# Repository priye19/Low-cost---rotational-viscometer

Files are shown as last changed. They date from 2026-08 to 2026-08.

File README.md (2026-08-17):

# Low-Cost Rotational Viscometer (LC-RV)

A 3D-printed concentric-cylinder viscometer that reads viscous drag with a $7 load cell on
the cup instead of a rotary transducer on the shaft.



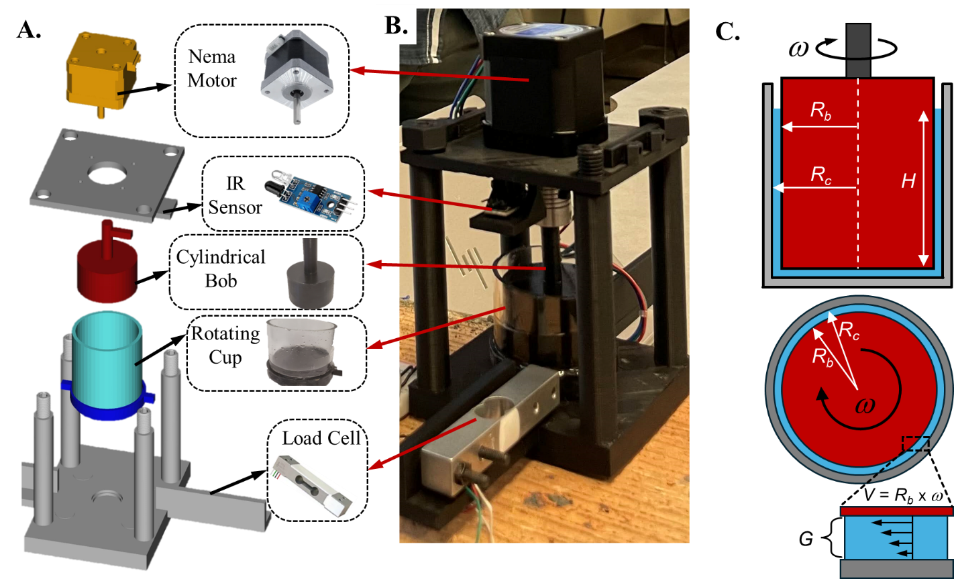
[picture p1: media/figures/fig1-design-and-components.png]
LC-RV design, printed parts and assembled instrument


<sub>Adapted with permission from *J. Chem. Educ.* **2025**, *102* (3), 1138-1145.
Copyright 2025 American Chemical Society.</sub>

## The problem

A bench rotational viscometer costs several thousand dollars. The LC-RV moves the
measurement off the shaft: the cup rides on a bearing so it is free to turn, and a
strain-gauge load cell holds it still and reports the restraining force. Everything else
is a stepper motor, an Arduino Nano, a length of acrylic tube and seven printed parts. It
was built for an undergraduate fluid mechanics course and written up in
*J. Chem. Educ.* (below).

## How it works

A NEMA 17 stepper spins the bob at a set speed inside the stationary cup. Viscous drag in
the annular gap tries to carry the cup round with it; the load cell resists and reads that
drag as a force. An IR sensor on a printed encoder disc reports the bob's actual speed
rather than trusting the step rate. Force, speed and the cell geometry then give the
viscosity:

```
omega = 2*pi*RPM/60
gdot  = omega*Rb/G
tau   = F / A                        A = 2*pi*Rc*h
mu    = tau / gdot
```

With the default 43 mm bob (Rb = 21.5 mm, Rc = 23.0 mm, G = 1.5 mm, h = 30.0 mm) that is
gdot = 14.3333 * omega and A = 4.3354e-3 m^2. Why a narrow gap makes the shear rate
uniform across it, the Taylor-number laminar limit, and what the instrument cannot do are
in [docs/theory.md](docs/theory.md).

## Specifications

| | |
|---|---|
| Bob speed | 5-400 RPM, set by potentiometer, measured by IR tachometer |
| Shear rate | about 7.5-600 s^-1 with the 43 mm bob |
| Viscosity | about 5 mPa·s to 2 Pa·s, the ceiling falling as speed rises |
| Sample volume | about 15 mL with the 43 mm bob |
| Annular gap | 1.5 mm default; 3.0, 4.5 and 6.0 mm bobs also printable |
| Cost | about $90 |

## What it measures

Glycerol solutions from 20 % to 100 % and mineral oil each gave a straight
shear-stress-against-shear-rate line whose slope is the viscosity; liquid soap gave an
apparent viscosity that falls as shear rate rises, which is shear thinning. Absolute
values run low against a commercial rheometer, so trends and orders of magnitude are
sound while individual numbers are not traceable. The bearing-friction floor, the load
cell ceiling and the non-Newtonian caveat are in [docs/theory.md](docs/theory.md).

## Build it

1. Print the core set from `hardware/cad/stl/`. The 40, 37 and 34 mm bobs are optional
   spares for the gap study.
2. Buy the bill of materials in [docs/build-guide.md](docs/build-guide.md).
3. Epoxy the acrylic tube into `cup_bottom`, press in the 608-2RS pivot bearing, and stack
   the frame on the M8 rods.
4. Wire it to `hardware/wiring-diagram.svg` and flash `firmware/LC-RV/`.
5. Run `firmware/calibration/calibrate/` with a known mass on the load cell and paste the
   calibration factor it prints into `firmware/LC-RV/config.h`.

Step-by-step instructions, dimensions and the wiring table are in
[docs/build-guide.md](docs/build-guide.md).

## Repository layout

| Directory | Contents |
|---|---|
| `docs/` | Build guide and the theory behind the equations above |
| `firmware/` | Arduino sketch, `config.h`, and the standalone calibration sketch |
| `hardware/` | Parametric CAD source, 10 STLs (seven for a build, three spare bobs), wiring diagram |
| `software/` | `analyze.py` and its requirements, for the logged CSV |
| `data/` | Reference measurements from the paper, as CSV |
| `media/` | Figures from the paper |

## Citation

If you build this or use these files, cite the article:

> Knutson, M.; Weerakoon, S. P.; Ticknor, C. J.; Yavitt, B. M.; Priye, A. Development and
> Implementation of a Low-Cost 3D-Printed Rotational Viscometer for Rheology and Fluid
> Mechanics Education. *J. Chem. Educ.* **2025**, *102* (3), 1138-1145.
> https://doi.org/10.1021/acs.jchemed.4c01490

`CITATION.cff` carries the same reference in machine-readable form.

## Licence

Code, CAD and documentation in this repository are MIT licensed; see [LICENSE](LICENSE).
The figures in `media/figures/` are reproduced from the article above and remain copyright
of the American Chemical Society. They are not covered by the MIT licence.

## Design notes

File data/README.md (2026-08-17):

# data/

Machine-readable form of the data behind the paper, transcribed from the source
workbook `Rotational Viscometer Data.xlsx`. Measured values are as published.
Where the workbook did not state a geometry or a label, it is inferred and the
inference is flagged in that file's header. Each file opens with `#` lines
giving its source sheet, geometry and caveats.

| File | Rows | What it is | Figure |
|---|---|---|---|
| `mineral-oil-gap-study.csv` | 852 | Mineral oil, 45 mm cup, bobs 39.5/40.5/41.5/42.5 mm, 140-400 rpm | none; recorded alongside Fig. 3 |
| `glycerol-80pct-gap-study.csv` | 3183 | 80 % glycerol. 45 mm cup with bobs 39.5-42.5 mm, and 46 mm cup with bobs 34/37/40/43 mm | Fig. 3 (45 mm cup), SFig. 2 (46 mm cup) |
| `glycerol-concentration-series.csv` | 2880 | Glycerol 20-100 % by mass, 46 mm cup, 43 mm bob, 120-400 rpm | Fig. 4A, 4B |
| `load-cell-response-timeseries.csv` | 193 | Load cell at 1 Hz, liquid soap at 125 rpm; rotation starts at t = 24 s | Fig. 2A |
| `stress-strain-summary.csv` | 27 | Per-speed summary for water, mineral oil and liquid soap | Fig. 2B, 2C |
| `glycerol-viscosity-reference.csv` | 22 | Literature glycerol viscosities at 20 and 25 C (Sheely 1932) | comparison bars in Fig. 4B |

## Columns

| Column | Unit | Meaning |
|---|---|---|
| `fluid`, `concentration_pct` | -, % by mass | sample identity |
| `cup_id_mm`, `bob_diameter_mm`, `gap_mm`, `wetted_height_mm` | mm | cell geometry for that row |
| `rpm`, `rpm_nominal` | rev/min | measured and set speed |
| `replicate` | - | index within one speed group |
| `time_s` | s | timeseries file only |
| `load_cell_g` | g | raw reading, and the only measured quantity |
| `wb_*` | as named | computed in the workbook and repeated on every row of a speed group, so not independent measurements |
| `source_sheet`, `source_column` | - | provenance in the workbook |

A `load_cell_g` of exactly 0, or slightly negative, in the dilute glycerol
columns is a genuine reading at or below the detection floor, not missing data.
An empty cell means no reading was taken.

The `wb_*` columns use the workbook's narrow-gap model, `gdot = omega*R_b/G`
and `tau = F/(2*pi*R_b*h)`. `software/analyze.py` ignores them and recomputes
shear rate and stress from the geometry each file states, using the cup-wall
area `A = 2*pi*R_c*h` rather than the workbook's bob area.

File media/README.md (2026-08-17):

# media/figures

| File | Shows |
|---|---|
| `fig0-graphical-abstract.png` | Graphical abstract |
| `fig1-design-and-components.png` | CAD model, assembled instrument with labelled parts, and the bob/cup geometry with R_b, R_c and the gap G |
| `fig2-performance-characterization.png` | Load cell trace before and during rotation, force vs motor speed, and the shear stress / shear rate curve with viscosity |
| `fig3-gap-width-effect.png` | Force vs speed for four gaps, and the collapse of stress and viscosity onto one line for gaps below 3 mm |
| `fig4-glycerol-validation.png` | Stress vs shear rate for glycerol 20-100 %, and measured viscosity against literature values |
| `fig5-classroom-and-assessment.png` | In-class demonstration, students using the instrument, and thematic coding of three post-lecture survey questions |
| `sfig1-electrical-schematic.png` | Circuit diagram of the Arduino, driver, load cell, IR sensor and OLED |
| `sfig2-large-gap-effect.png` | Gaps above 3 mm, where the narrow-gap approximation breaks down |
| `sfig3-inclined-plane.png` | Ketchup inclined-plane exercise students did before the class |
| `sfig4-bill-of-materials.png` | Components and cost breakdown |

Figures are from Knutson et al., *J. Chem. Educ.* 2025, 102 (3), 1138-1145
(doi 10.1021/acs.jchemed.4c01490), copyright American Chemical Society. They
are reproduced here for reference and are not under this repository's licence.

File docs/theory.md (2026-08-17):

# Theory

A concentric-cylinder (Couette) viscometer. A bob of radius `R_b` spins at angular velocity
`omega` inside a stationary cup of inner radius `R_c`, with fluid filling the annulus over a
wetted height `h`. Viscous drag tries to turn the cup; a load cell holds it and reads the
restraining force `F`. As built: `R_c` = 23.0 mm, `R_b` = 21.5 mm (43 mm bob), gap
`G = R_c - R_b` = 1.5 mm, `h` = 30.0 mm.

## Shear in the annulus

The bob wall moves at `omega*R_b` and the cup wall is stationary, so the fluid between them
is sheared. When the gap is small next to the radii, the curvature of the annulus makes
little difference and the flow is effectively the flow between two flat plates `G` apart:
the velocity falls linearly across the gap and the shear rate is the same everywhere in it.
The fluid drags on the wetted band of cup wall, and the load cell reads that drag as a
force. Three lines then give the viscosity:

    omega = 2*pi*RPM/60           rad/s
    gdot  = omega*R_b/G           1/s     shear rate in the gap
    A     = 2*pi*R_c*h            m^2     wetted area of the cup wall
    tau   = F/A                   Pa      F in newtons
    mu    = tau/gdot              Pa.s

For the 43 mm bob, `gdot` = 14.3333*`omega` and `A` = 4.3354e-3 m^2, so 5-400 RPM spans
7.5-600 s^-1. With force read in grams that is `mu` = 0.157814*`F_g`/`omega`.

The linear profile is an assumption of the method, not a result. It holds while `G` is small
compared with `R_b`, which is why the default gap is 1.5 mm on a 21.5 mm bob. The 40, 37 and
34 mm bobs open it to 3.0, 4.5 and 6.0 mm; the wider the gap, the weaker the assumption, so
those results are less reliable than the default.

Laminar flow is the other assumption. With the inner cylinder turning, the flow breaks into
Taylor vortices above `Ta = omega^2*R_b*G^3/nu^2 = 1708`, which at 400 RPM and `G` = 1.5 mm
is `nu` = 8.6e-6 m^2/s; `analyze.py` computes `Ta` and leaves any point past it out of the
fit.

## Limits

- Friction in the cup bearing sets a floor near 3-5 mPa.s. Water, at 1 mPa.s, is below it
  and cannot be measured on this instrument.
- The 100 g load cell sets the ceiling, and since force grows with speed the ceiling falls
  as speed rises: about 6 Pa.s at 25 RPM, 1.5 Pa.s at 100 RPM, 0.5 Pa.s at 300 RPM. Thick
  fluids have to be run slowly.
- There is no temperature control and no temperature sensor. Viscosity is strongly
  temperature dependent (glycerol about 7 % per degC), so note the room temperature with a
  thermometer and let the sample sit until it has settled.
- For a non-Newtonian fluid the reported number is an apparent viscosity at the shear rate
  above, not a material constant.
- Absolute values run low against a commercial rheometer. Trends and orders of magnitude
  hold; individual numbers are not traceable.

Knutson et al., *J. Chem. Educ.* **2025**, *102* (3), 1138-1145.
https://doi.org/10.1021/acs.jchemed.4c01490

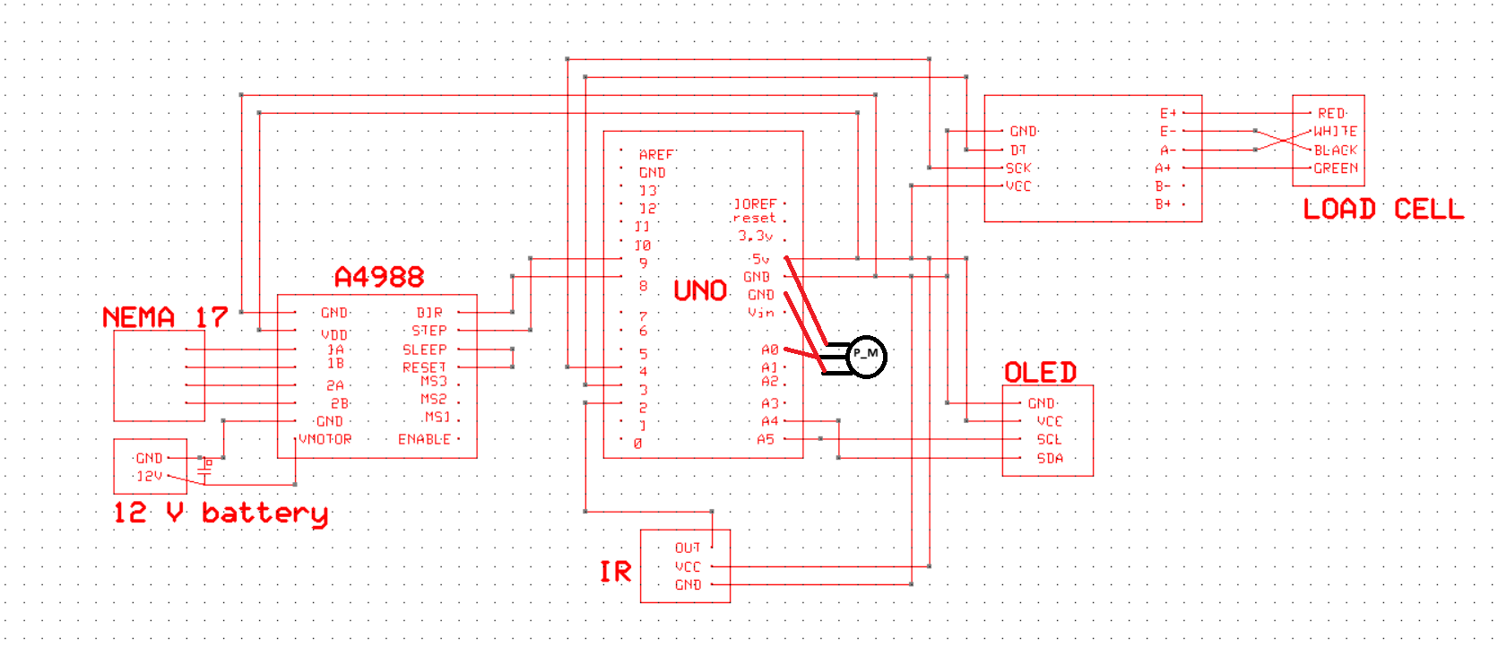
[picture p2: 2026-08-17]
media/figures/sfig1-electrical-schematic.png

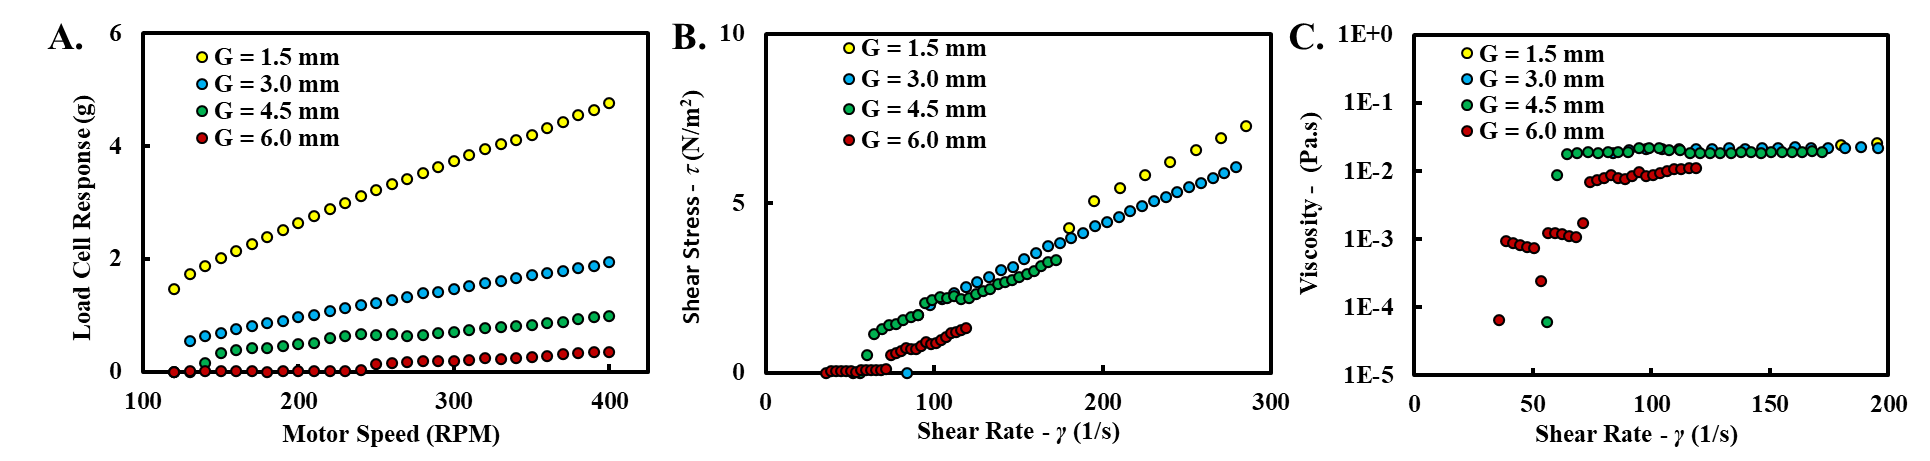
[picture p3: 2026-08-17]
media/figures/sfig2-large-gap-effect.png

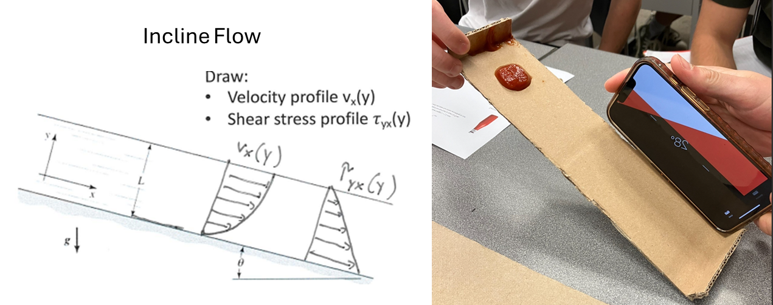
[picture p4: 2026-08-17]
media/figures/sfig3-inclined-plane.png

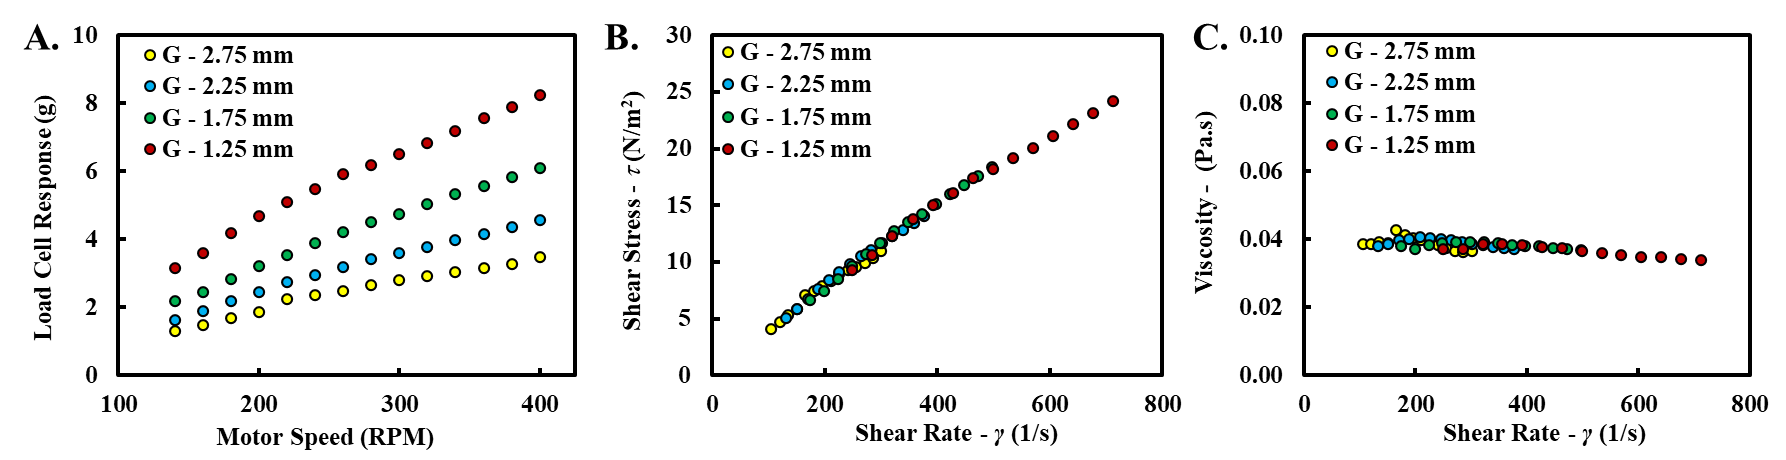
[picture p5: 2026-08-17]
media/figures/fig3-gap-width-effect.png

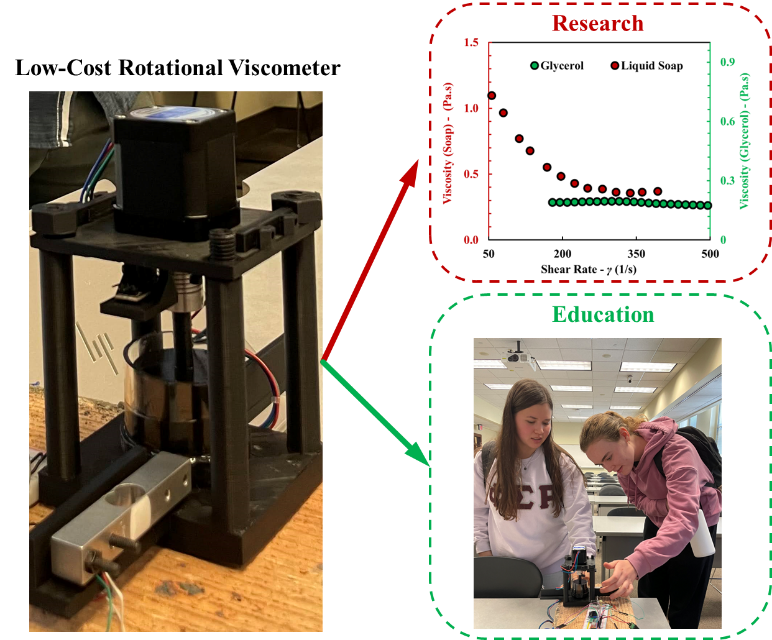
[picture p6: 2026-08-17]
media/figures/fig0-graphical-abstract.png

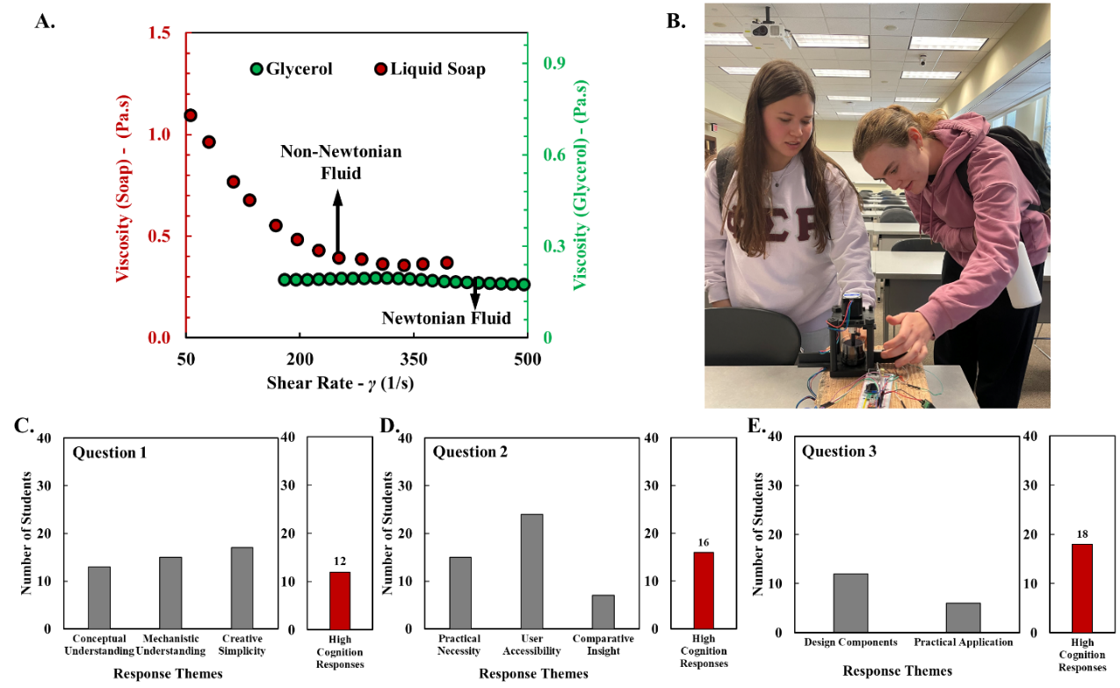
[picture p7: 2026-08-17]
media/figures/fig5-classroom-and-assessment.png

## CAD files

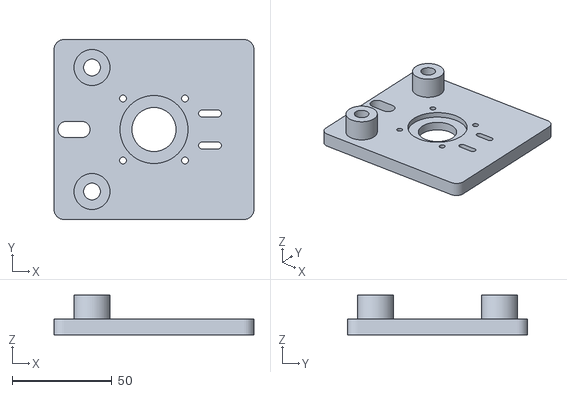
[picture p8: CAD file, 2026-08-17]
hardware/cad/stl/motor_plate.stl
100.0 x 90.0 x 20.0

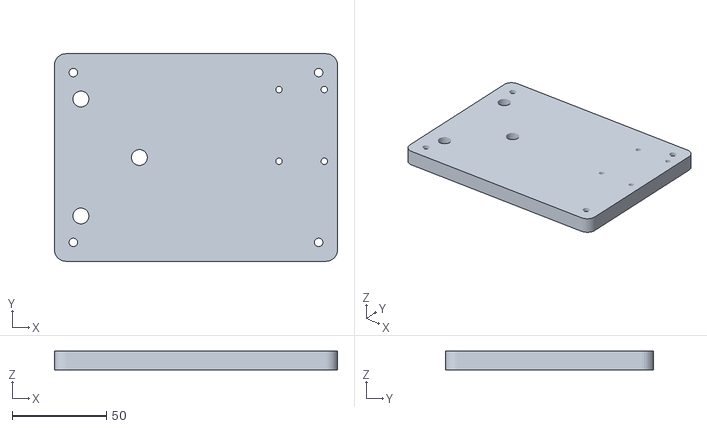
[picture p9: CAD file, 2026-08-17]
hardware/cad/stl/base_plate.stl
150.0 x 110.0 x 10.0

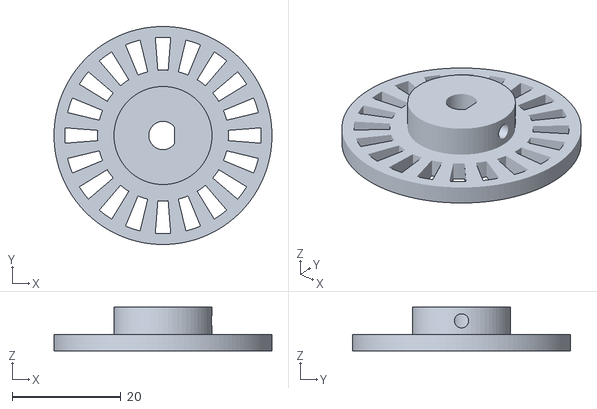
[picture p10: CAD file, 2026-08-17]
hardware/cad/stl/encoder_disc.stl
40.0 x 40.0 x 8.00

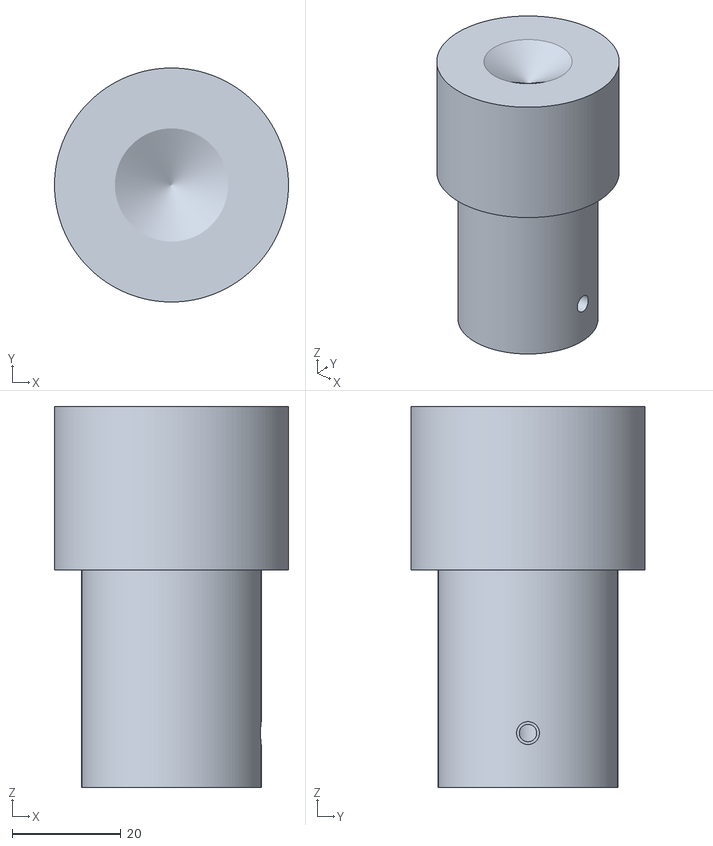
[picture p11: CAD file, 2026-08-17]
hardware/cad/stl/bob_43mm.stl
43.0 x 43.0 x 70.0

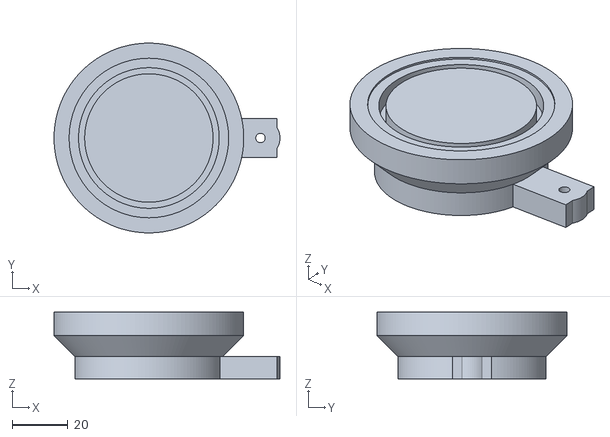
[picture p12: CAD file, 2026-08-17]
hardware/cad/stl/cup_bottom.stl
81.0 x 68.0 x 24.0

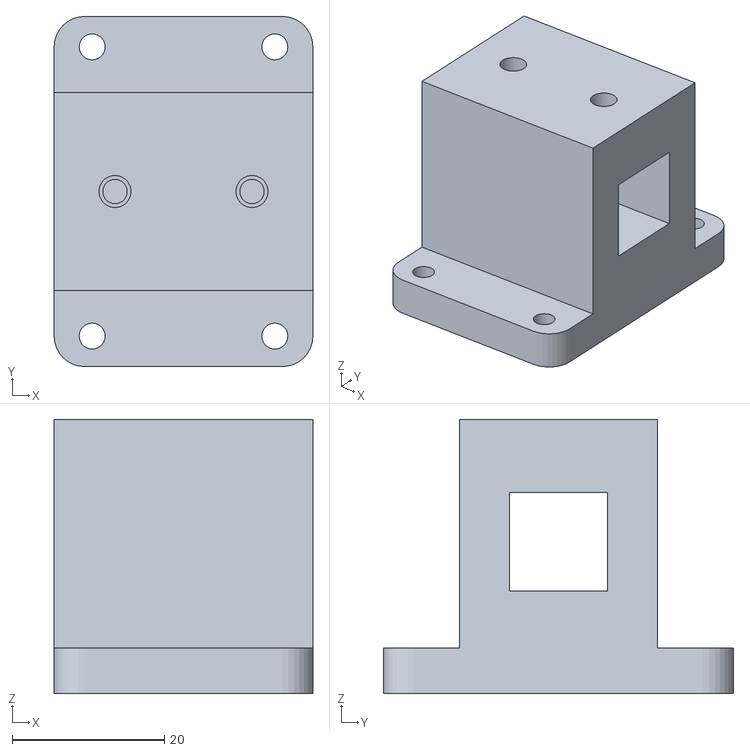
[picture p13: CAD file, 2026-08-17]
hardware/cad/stl/loadcell_mount.stl
34.0 x 46.0 x 36.0

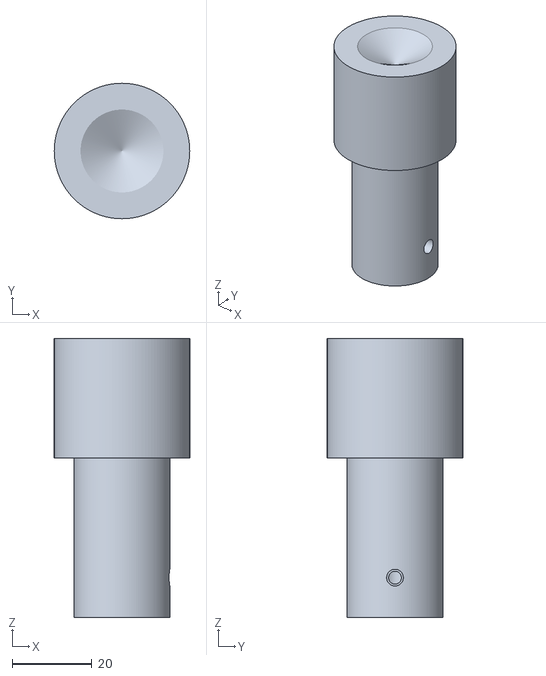
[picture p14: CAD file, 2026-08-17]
hardware/cad/stl/bob_34mm.stl
34.0 x 34.0 x 70.0

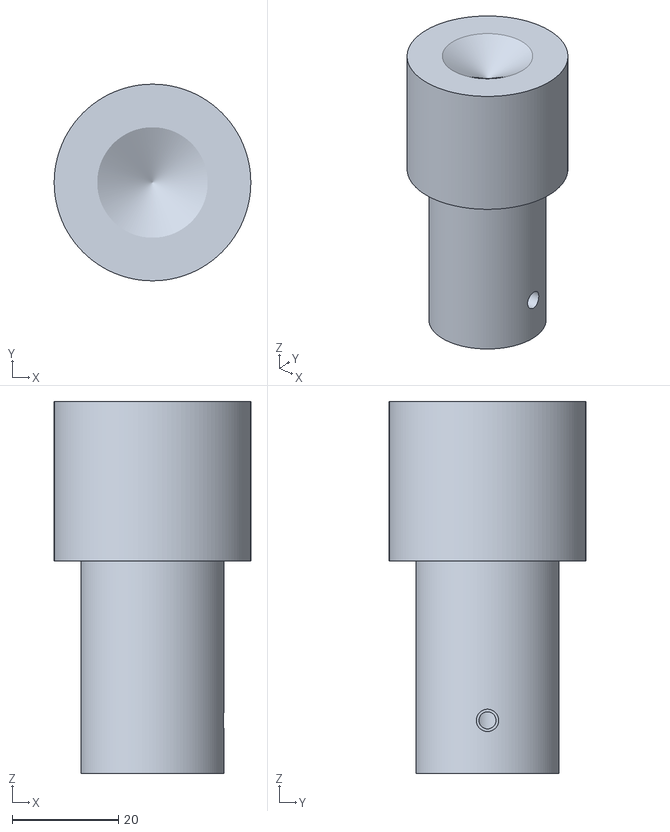
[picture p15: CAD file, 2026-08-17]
hardware/cad/stl/bob_37mm.stl
37.0 x 37.0 x 70.0

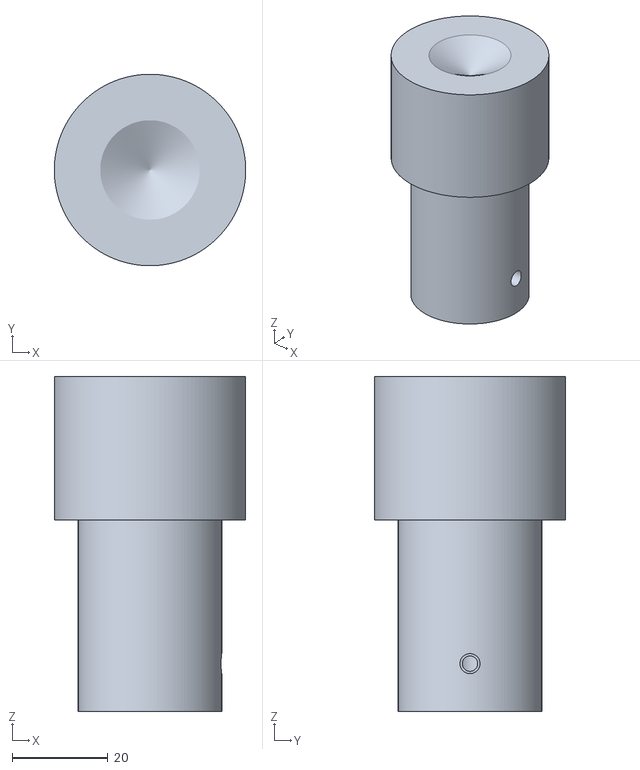
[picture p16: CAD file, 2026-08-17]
hardware/cad/stl/bob_40mm.stl
40.0 x 40.0 x 70.0

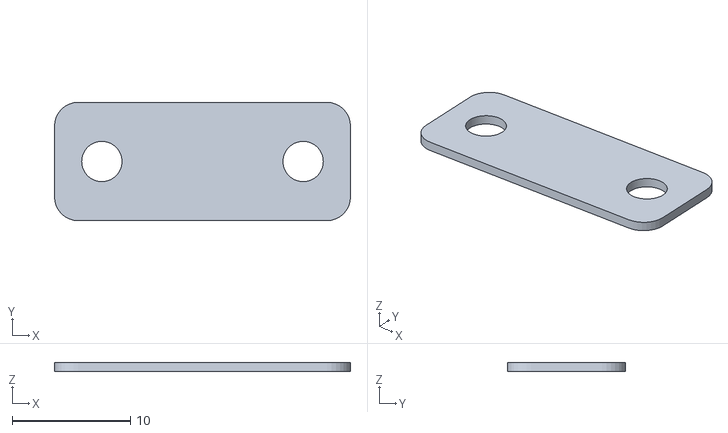
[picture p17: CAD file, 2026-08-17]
hardware/cad/stl/flexure_link.stl
25.0 x 10.0 x 0.8

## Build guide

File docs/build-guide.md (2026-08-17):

# Build guide

Everything needed to go from an empty bench to a first viscosity measurement, in build
order. Print, assemble, wire, flash, calibrate, measure.

## 1. Bill of materials

| Part | Notes | Qty | ~USD |
|---|---|---|---|
| Arduino Nano | | 1 | 8 |
| A4988 stepper driver | | 1 | 3 |
| NEMA 17 stepper motor | 5 mm shaft with a flat | 1 | 12 |
| 12 V DC supply | 2 A | 1 | 8 |
| Load cell, 100 g | straight bar type | 1 | 7 |
| HX711 amplifier board | | 1 | 3 |
| SSD1306 OLED, 128x64 | I2C version, address 0x3C | 1 | 5 |
| IR slotted opto sensor | LM393 module, digital OUT | 1 | 3 |
| Potentiometer, 10 k | | 1 | 1 |
| 608-2RS bearing | | 1 | 2 |
| Acrylic tube | 50 mm OD / 46 mm ID, 100 mm long | 1 | 7 |
| M8 threaded rod, nuts, washers | 300 mm of rod | 1 set | 5 |
| M3 screws and nuts | | 1 set | 5 |
| Electrolytic capacitor, 100 uF | 25 V or higher | 1 | 1 |
| PLA filament | | 300 g | 8 |
| Two-part epoxy | | 1 | 5 |
| Hook-up wire and jumpers | | 1 set | 3 |
| | | Total | 86 |

Tools: 3D printer, digital calipers, soldering iron, hex keys, small screwdrivers, an
8 mm and a 13 mm spanner, wire cutters and strippers, a multimeter.

## 2. Printing

STLs are in `hardware/cad/stl/`. PLA, 0.2 mm layers, 20 % infill, no supports.

| Part | Qty | Orientation |
|---|---|---|
| `base_plate` | 1 | |
| `motor_plate` | 1 | |
| `cup_bottom` | 1 | tube socket facing up |
| `loadcell_mount` | 1 | |
| `flexure_link` | 1 | flat on the bed, layers running across the thin section |
| `encoder_disc` | 1 | |
| `bob_43mm` | 1 | shaft bore down |
| `bob_40mm` | 1 | shaft bore down |
| `bob_37mm` | 1 | shaft bore down |
| `bob_34mm` | 1 | shaft bore down |

The core set is the seven parts through `bob_43mm`: about 239 g and 10.0 h of printing,
as estimated by `hardware/cad/src/build.py`.

`bob_40mm`, `bob_37mm` and `bob_34mm` are only needed to repeat the gap study.

Before assembling, measure the 22 mm bearing bore in `cup_bottom` with calipers; if the
print came out undersize, ream or sand it until a 608 bearing is a firm push fit.

## 3. Assembly

1. Cut two M8 uprights (about 140 mm) from the threaded rod. Pass each through its hole
   in `base_plate` and lock it with an M8 nut and washer above and below the plate.
2. Fit the M8 pivot bolt upward through the centre hole of `base_plate`, locked with an
   M8 nut and washer under the plate. Press a 608-2RS bearing onto the bolt and secure
   it with a second nut. The bearing outer race carries the cup.
3. Roughen the last 10 mm of the acrylic tube with abrasive paper, mix the epoxy, and
   seat the tube fully into the socket in `cup_bottom`. Wipe the squeeze-out from the
   inside before it sets, keep the tube square to the base, and leave it to cure for
   24 h. Fill it with water afterwards and confirm the joint does not weep.
4. Push the cup assembly down onto the pivot bearing until the 22 mm bore is fully
   seated. Spin it by hand: it should coast freely with no wobble.
5. Bolt `loadcell_mount` to `base_plate` with two M3x12 screws and nuts.
6. Screw the fixed end of the load cell to `loadcell_mount` with two M3x8 screws, free
   end pointing at the cup. Note which end the wires leave from and keep that end fixed.
   `tau = F/A` treats the reading as the tangential force at the cup wall; the printed arm
   sets where the cell bears, so just fit the link square and unstressed.
7. Fasten `flexure_link` between the free end of the load cell and the arm on
   `cup_bottom`, one M3x8 screw at each end. The link should be straight and unstressed
   with the cup at rest.
8. Slide `motor_plate` onto the two uprights and clamp it with an M8 nut above and below
   each upright. Leave the nuts finger-tight for now; step 12 sets the final height.
9. Bolt the NEMA 17 to `motor_plate` with four M3x8 screws, shaft pointing down through
   the plate's clearance hole.
10. Press `encoder_disc` onto the motor shaft above the plate. Bolt the IR sensor module
    to the plate with two M3x10 screws so the disc's slots pass cleanly through its gap
    without touching either side.
11. Press `bob_43mm` onto the 5 mm motor shaft below the plate and tighten its grub screw
    onto the flat of the shaft.
12. Set the immersion. Slacken the `motor_plate` nuts and lower the assembly until the
    flat underside of the bob sits 5 mm above the cup floor, then lock the nuts. Filling
    to the line 35 mm above the cup floor now wets 30 mm of the bob.
13. Turn the bob one full revolution by hand and check it is concentric in the cup, with
    the 1.5 mm gap even all the way round.

Nothing may touch the cup except the pivot bearing and the flexure link. Anything else in
contact adds its own restoring force and the instrument reads low.

## 4. Wiring

| Arduino | To |
|---|---|
| D2 | IR sensor OUT |
| D3 | HX711 DT |
| D4 | HX711 SCK |
| D8 | A4988 DIR |
| D9 | A4988 STEP (Timer1 OC1A - must be D9) |
| A0 | potentiometer wiper |
| A4 | OLED SDA |
| A5 | OLED SCL |

A4988 MS1, MS2 and MS3 go to 5 V for 1/16 microstepping, 3200 steps per revolution.
The 12 V supply feeds VMOT with the 100 uF capacitor directly across VMOT and its
ground; fit it before applying power. Everything else runs from the Nano's 5 V rail, and
the 12 V supply and the Arduino share one ground.

LC-RV wiring diagram

Set the A4988 current limit before the first run: with the driver powered and the motor
disconnected, measure Vref on the trim pot and set it from `I = Vref / (8 * Rsense)`.
Read Rsense off the board's sense resistors and choose I at or below the motor's rated
phase current.

## 5. Firmware

Install three libraries through the Arduino IDE Library Manager:

| Library | Author |
|---|---|
| HX711 Arduino Library | bogde |
| Adafruit GFX Library | Adafruit |
| Adafruit SSD1306 | Adafruit |

Open `firmware/LC-RV/LC-RV.ino` and edit `config.h` to match what you built:

| Define | Set to |
|---|---|
| `BOB_DIAMETER_MM` | 43.0 for the default bob, otherwise 40.0 / 37.0 / 34.0 |
| `CUP_RADIUS_MM` | 23.0 (half of the 46 mm tube bore) |
| `WETTED_HEIGHT_MM` | 30.0, the wetted bob height set in assembly step 12 |
| `LOADCELL_CAPACITY_G` | 100.0 |
| `CALIBRATION_FACTOR` | filled in by section 6 |

Select Tools > Board > Arduino Nano and the ATmega328P processor, pick the port, and
upload. Open the serial monitor at 115200 baud: the sketch prints a CSV header and then
one line per reading. Readings before calibration are the right shape but the wrong
size.

## 6. Calibration

The HX711 gives raw counts; the firmware needs counts per gram. Calibrate the cell on its
own, with `flexure_link` unbolted and the motor unpowered, so nothing but the mass loads
it. Upload `firmware/calibration/calibrate/calibrate.ino`, set a small empty pan on the
free end of the cell and tare. Put a known mass in the pan, let the reading settle, and
the sketch averages the counts and prints `CALIBRATION_FACTOR` in counts per gram.

Repeat with one or two other masses across the range you expect to measure. The factor
should come out the same each time; if it drifts, the cell is touching something or the
mount is flexing. Paste the value into `config.h`, re-upload `LC-RV.ino`, and refit the
flexure link.

## 7. First measurement

Mix 80 % glycerol by mass: 80.0 g of glycerol to 20.0 g of distilled water, stirred
until uniform and then left to stand until the entrained bubbles have cleared.

Fill the cup to the 35 mm line, check the bob still turns freely, and power up. Set the
potentiometer to about 300 RPM and let the reading stabilise before recording anything.
At that speed 80 % glycerol, near 0.06 Pa.s at room temperature, should read about 12 g
on the load cell: `F_g = 6.3366 * mu * omega`, with `omega` = 31.4 rad/s. Save the serial
stream to `run.csv` with any terminal that can log a port at 115200 baud, keeping the
header line.
Let it run for a minute or two, stop it, and analyse:

    python software/analyze.py run.csv

Literature viscosities for glycerol solutions at 20 and 25 C are in
`data/reference/glycerol-viscosity-reference.csv`. Expect the trend to be right and the
absolute value to come out under the literature figure; see
[theory.md](theory.md) for why.

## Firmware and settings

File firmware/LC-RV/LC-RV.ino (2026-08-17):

/* LC-RV -- low-cost rotational viscometer.  Arduino Nano (ATmega328P).

   A stepper spins a bob inside a cup of sample fluid.  The cup turns on
   a bearing and is held back by a load cell, so viscous drag in the
   annulus appears as a force at the cup wall.  Force, speed and
   geometry give shear rate, shear stress and viscosity; all three are
   computed here and streamed as CSV at 115200 baud.

   Step pulses come out of Timer1 in hardware on D9, so nothing this
   sketch does in software can disturb the rotation.  Nothing in loop()
   blocks either: the HX711 is polled with is_ready(), never through
   get_units(n), which averages n conversions and stalls for roughly
   half a second per call.

   Everything you may want to change lives in config.h.

   Knutson, M.; Weerakoon, S. P.; Ticknor, C. J.; Yavitt, B. M.;
   Priye, A. J. Chem. Educ. 2025, 102 (3), 1138-1145.
   https://doi.org/10.1021/acs.jchemed.4c01490 */

#include <util/atomic.h>
#include <Wire.h>
#include <Adafruit_GFX.h>
#include <Adafruit_SSD1306.h>
#include <HX711.h>
#include "config.h"

/* SRAM: the statics below plus the 1024-byte frame buffer that
   Adafruit_SSD1306::begin() malloc's take most of the Nano's 2 KB.
   That leaves a few hundred bytes of stack -- enough here, but it is
   why there is no String and no second buffer anywhere below. */

/* ---- Geometry, folded to SI at compile time ------------------------ */
/* K_SHEAR: narrow-gap shear rate, gdot = K_SHEAR*w, with R_b/G = 14.333
            for the 43 mm bob.
   AREA:    wetted area of the cup wall, 2*pi*Rc*h = 4.3354e-3 m^2 at
            h = 30 mm.  The load-cell force acts over it: tau = F/A. */
static const float R_B     = BOB_DIAMETER_MM * 0.0005f;
static const float R_C     = CUP_RADIUS_MM * 0.001f;
static const float G_STD   = 9.80665f;
static const float K_SHEAR = R_B / (GAP_MM * 0.001f);
static const float AREA    = 6.283185f * R_C * (WETTED_HEIGHT_MM * 0.001f);

/* ---- Speed --------------------------------------------------------- */
/* Timer1 runs CTC with prescaler 1 and toggles OC1A, so one step pulse
   is two compare matches:  OCR1A = F_CPU/2 * 60 / (STEPS_PER_REV*RPM) - 1
   = 150000/RPM - 1.  400 RPM -> 374, 5 RPM -> 29999.  Below 5 RPM the
   bearing friction dominates, above 400 the motor loses steps. */
static const float    MIN_RPM = 5.0f;
static const float    MAX_RPM = 400.0f;
static const uint32_t OCR_NUM = (F_CPU / 2UL) * 60UL / STEPS_PER_REV;

/* ---- State --------------------------------------------------------- */
HX711 scale;
Adafruit_SSD1306 oled(128, 64, &Wire, -1);

static float g_rpmSet  = MIN_RPM;   /* what Timer1 is doing now         */
static float g_rpmMeas = 0.0f;      /* what the IR sensor sees          */
static bool  g_tachoOk = false;
static float g_counts  = 0.0f;      /* filtered load-cell counts        */
static float g_zero    = 0.0f;      /* counts with the cup unloaded     */
static bool  g_cellOk  = false;
static bool  g_oledOk  = false;
static float g_stress  = 0.0f;      /* kept for the display             */
static float g_visc    = 0.0f;

static volatile uint32_t g_sumUs  = 0;   /* written by the INT0 handler */
static volatile uint32_t g_lastUs = 0;
static volatile uint16_t g_nPulse = 0;
static volatile bool     g_havePulse = false;

static uint32_t g_tSpeed = 0, g_tTacho = 0, g_tRow = 0, g_tOled = 0;
static uint32_t g_tWarn = 0;

/* True once every `period` ms.  millis() differences are unsigned, so
   this stays correct across the 49-day rollover. */
static bool due(uint32_t *t, uint16_t period)
{
  const uint32_t now = millis();
  if (now - *t < period) {
    return false;
  }
  *t = now;
  return true;
}

/* ---- Motor --------------------------------------------------------- */
static void motorSetRpm(float rpm)
{
  if (rpm < MIN_RPM) rpm = MIN_RPM;
  if (rpm > MAX_RPM) rpm = MAX_RPM;
  const uint16_t ocr = (uint16_t)((float)OCR_NUM / rpm + 0.5f) - 1;
  ATOMIC_BLOCK(ATOMIC_RESTORESTATE) {
    OCR1A = ocr;
    /* Rewind if the counter has already run past the new TOP; otherwise
       a slow-down leaves a gap of up to 4 ms in the step train. */
    if (TCNT1 > ocr) {
      TCNT1 = 0;
    }
  }
  g_rpmSet = rpm;
}

/* Follow the knob, but slew at 400 RPM/s: a stepper commanded from 5 to
   400 RPM in one step just stalls.  The 1 RPM deadband also absorbs the
   ADC jitter on A0. */
static void speedTick()
{
  const float want = MIN_RPM +
                     analogRead(PIN_POT) * ((MAX_RPM - MIN_RPM) / 1023.0f);
  float d = want - g_rpmSet;
  if (fabs(d) < 1.0f) {
    return;
  }
  if (d >  20.0f) d =  20.0f;
  if (d < -20.0f) d = -20.0f;
  motorSetRpm(g_rpmSet + d);
}

/* ---- Tachometer ---------------------------------------------------- */
static void tachoIsr()
{
  const uint32_t now = micros();
  if (g_havePulse) {
    g_sumUs += now - g_lastUs;
    g_nPulse++;
  }
  g_lastUs = now;
  g_havePulse = true;
}

static void tachoUpdate()
{
  uint32_t sum, last;
  uint16_t n;
  ATOMIC_BLOCK(ATOMIC_RESTORESTATE) {
    sum = g_sumUs;
    n = g_nPulse;
    last = g_lastUs;
    g_sumUs = 0;
    g_nPulse = 0;
  }
  if (n > 0) {
    g_rpmMeas = 60000000.0f / (((float)sum / n) * IR_PULSES_PER_REV);
    g_tachoOk = true;
  } else if (micros() - last > 3000000UL) {
    /* At 5 RPM the pulses are 600 ms apart, so an empty window is not
       yet evidence of a stall; three seconds of silence is. */
    g_rpmMeas = 0.0f;
    g_tachoOk = false;
  }
}

/* ---- Load cell ----------------------------------------------------- */
/* is_ready() is a single digitalRead of DOUT; read() then takes about
   0.3 ms.  The HX711 delivers 10 samples per second, so this smooths
   with a light exponential average rather than a long block average. */
static void loadCellPoll()
{
  if (!scale.is_ready()) {
    return;
  }
  const float raw = (float)scale.read();
  g_counts = g_cellOk ? g_counts + 0.25f * (raw - g_counts) : raw;
  g_cellOk = true;
}

/* ---- Output -------------------------------------------------------- */
static void emitRow()
{
  const float rpm = g_tachoOk ? g_rpmMeas : g_rpmSet;
  const float w = rpm * 0.10471976f;              /* 2*pi*RPM/60 [rad/s] */
  const float force_g = (g_counts - g_zero) / CALIBRATION_FACTOR;
  const float gdot = K_SHEAR * w;
  /* tau = F/A, with F = force_g grams weight on the cell. */
  g_stress = force_g * G_STD * 0.001f / AREA;
  g_visc = (gdot > 0.0f) ? g_stress / gdot : 0.0f;

  Serial.print(millis() * 0.001f, 2);
  Serial.print(',');
  Serial.print(rpm, 1);
  Serial.print(',');
  Serial.print(force_g, 3);
  Serial.print(',');
  Serial.print(gdot, 2);
  Serial.print(',');
  Serial.print(g_stress, 4);
  Serial.print(',');
  Serial.println(g_visc, 5);

  if (fabs(force_g) > LOADCELL_CAPACITY_G && due(&g_tWarn, 5000)) {
    Serial.println(F("# load cell near or past full scale"));
  }
}

static void oledUpdate()
{
  oled.clearDisplay();
  oled.setCursor(0, 0);
  oled.print(F("RPM     "));
  oled.print(g_tachoOk ? g_rpmMeas : g_rpmSet, 1);
  oled.setCursor(0, 16);
  oled.print(F("stress  "));
  oled.print(g_stress, 3);
  oled.print(F(" Pa"));
  oled.setCursor(0, 32);
  oled.print(F("visc    "));
  oled.print(g_visc, 4);
  oled.print(F(" Pas"));
  oled.display();
}

/* ---- Setup and loop ------------------------------------------------ */
void setup()
{
  Serial.begin(115200);

  pinMode(PIN_DIR, OUTPUT);
  digitalWrite(PIN_DIR, HIGH);
  pinMode(PIN_STEP, OUTPUT);
  ATOMIC_BLOCK(ATOMIC_RESTORESTATE) {
    TCCR1A = _BV(COM1A0);               /* toggle OC1A (D9) on match     */
    TCCR1B = _BV(WGM12) | _BV(CS10);    /* CTC, prescaler 1              */
    TIMSK1 = 0;                         /* no Timer1 interrupt needed    */
    TCNT1 = 0;
  }
  motorSetRpm(MIN_RPM);

  pinMode(PIN_TACHO, INPUT);
  attachInterrupt(digitalPinToInterrupt(PIN_TACHO), tachoIsr, RISING);

  /* Zero the load cell once, before anything turns.  Averaging blocks
     for about a second here, which is harmless with the motor idle. */
  scale.begin(PIN_HX711_DT, PIN_HX711_SCK);
  if (scale.wait_ready_timeout(1000)) {
    g_zero = (float)scale.read_average(10);
    g_counts = g_zero;
    g_cellOk = true;
  } else {
    Serial.println(F("# no HX711 on D3/D4"));
  }

  g_oledOk = oled.begin(SSD1306_SWITCHCAPVCC, OLED_ADDR);
  if (g_oledOk) {
    oled.setTextColor(SSD1306_WHITE);
    oled.setTextSize(1);
  } else {
    Serial.println(F("# no SSD1306 at 0x3C"));
  }

  Serial.println(
      F("t_s,rpm,force_g,shear_rate_1s,stress_Pa,viscosity_Pas"));
}

void loop()
{
  loadCellPoll();
  if (due(&g_tSpeed, 50)) {
    speedTick();
  }
  if (due(&g_tTacho, 1000)) {
    tachoUpdate();
  }
  if (due(&g_tRow, 250)) {
    emitRow();
  }
  if (g_oledOk && due(&g_tOled, 500)) {
    oledUpdate();
  }
}

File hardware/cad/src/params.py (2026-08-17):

"""Parametric dimensions for the LC-RV printed parts.

The dimensions here mirror ``firmware/LC-RV/config.h``; keep them in step by
hand.

UNITS
-----
Everything in this file is millimetres, degrees, or dimensionless.

COORDINATE CONVENTIONS
----------------------
* Every part is modelled in its own local frame with ``z = 0`` on the print bed
  and the part already in its recommended print orientation, so the exported
  STL can be dropped straight into a slicer with no rotation.
* For the parts that sit on the instrument axis (``base_plate``,
  ``motor_plate``, ``cup_bottom``) the local ``x = y = 0`` line is the cup /
  bob rotation axis, so the parts stack by simple translation in ``z``.
* ``+x`` points from the cup axis toward the load cell (the arm
  direction).  ``+y`` is the tangential direction in which the load cell is
  loaded.
"""

from __future__ import annotations

import math

# --------------------------------------------------------------------------
# 0.  Identity
# --------------------------------------------------------------------------
PROJECT = "Low-Cost Rotational Viscometer (LC-RV)"

# --------------------------------------------------------------------------
# 1.  GEOMETRY
# --------------------------------------------------------------------------
R_C_MM = 23.000            # cup inner radius
CUP_ID_MM = 46.000         # cup inner diameter (= 2 * R_C_MM)
R_B_MM = 21.500            # default bob working radius (43 mm bob)
GAP_MM = 1.500             # default annular gap
R_S_MM = 16.500            # default bob shank radius
H_W_MM = 30.000            # bob working-cylinder height (wetted)
BOB_FLOOR_CLEARANCE_MM = 5.000   # bob underside -> cup floor clearance (c)
H_FILL_MM = 35.000         # fill height above cup floor (= c + h_w)
CUP_ARM_HOLE_R_MM = 40.000  # cup axis -> M3 flexure-link hole

# Acrylic cup tube (bought part, not printed)
TUBE_OD_MM = 50.0
TUBE_ID_MM = 46.0
TUBE_WALL_MM = 2.0
TUBE_LENGTH_MM = 100.0

# Bob bottom feature: 120 deg included-angle conical recess, 6.0 mm deep.
BOB_CONE_INCLUDED_ANGLE_DEG = 120.0
BOB_CONE_DEPTH_MM = 6.0
BOB_CONE_MOUTH_RADIUS_MM = 10.39   # canonical; = 6.0 * tan(60 deg) = 10.3923

# Bob envelope: total length 70 mm = 5 mm blind hub + 35 mm shank + 30 mm
# working cylinder (working cylinder at the bottom in use).
BOB_TOTAL_LENGTH_MM = 70.0
BOB_HUB_LENGTH_MM = 5.0
BOB_SHANK_LENGTH_MM = 35.0
BOB_WORKING_LENGTH_MM = 30.0       # == H_W_MM
BOB_SHANK_DIA_OFFSET_MM = 10.0     # shank dia = working dia - 10.0, every variant

# Motor coupling in the bob hub end
BOB_DBORE_DIA_MM = 5.0             # 5 mm D-bore for the NEMA 17 shaft
BOB_DBORE_DEPTH_MM = 20.0
BOB_DBORE_FLAT_DEPTH_MM = 0.5      # standard flat on a 5 mm NEMA 17 shaft

# The four printable bobs: working_dia_mm, R_b, gap, shank_dia_mm, R_s, and
# the shear-rate factor k = R_b/gap, so that gdot = k * omega.
BOBS = {
    "bob_43mm": dict(working_dia=43.0, R_b=21.5, gap=1.5, shank_dia=33.0,
                     R_s=16.5, k=14.3333, default=True),
    "bob_40mm": dict(working_dia=40.0, R_b=20.0, gap=3.0, shank_dia=30.0,
                     R_s=15.0, k=6.6667, default=False),
    "bob_37mm": dict(working_dia=37.0, R_b=18.5, gap=4.5, shank_dia=27.0,
                     R_s=13.5, k=4.1111, default=False),
    "bob_34mm": dict(working_dia=34.0, R_b=17.0, gap=6.0, shank_dia=24.0,
                     R_s=12.0, k=2.8333, default=False),
}
DEFAULT_BOB = "bob_43mm"
K_DEFAULT = 14.3333

# --------------------------------------------------------------------------
# 2.  PRINTED-PART ENVELOPES
# --------------------------------------------------------------------------
BASE_PLATE_X_MM = 150.0
BASE_PLATE_Y_MM = 110.0
BASE_PLATE_T_MM = 10.0

MOTOR_PLATE_X_MM = 100.0
MOTOR_PLATE_Y_MM = 90.0
MOTOR_PLATE_T_MM = 8.0

CUP_BOTTOM_DIA_MM = 68.0

ENCODER_DISC_DIA_MM = 40.0
ENCODER_SLOTS = 20                 # == IR_PULSES_PER_REV in config.h

FLEXURE_T_MM = 0.8
FLEXURE_W_MM = 10.0
FLEXURE_L_MM = 25.0

# Printer envelope. Every part must fit inside it.
BED_X_MM = 200.0
BED_Y_MM = 200.0
BED_Z_MM = 200.0

# --------------------------------------------------------------------------
# 3.  BOUGHT HARDWARE
# --------------------------------------------------------------------------
BEARING_608_ID_MM = 8.0
BEARING_608_OD_MM = 22.0
BEARING_608_W_MM = 7.0
BEARING_608_INNER_RACE_FACE_R_MM = 6.0   # safe clamp radius, clears the 2RS seal

NEMA17_BOLT_SQUARE_MM = 31.0       # bolt circle is a 31.0 mm square
NEMA17_BODY_MM = 42.0
NEMA17_REGISTER_DIA_MM = 22.0      # pilot boss -> motor_plate bore
NEMA17_SHAFT_DIA_MM = 5.0
NEMA17_SHAFT_LENGTH_MM = 24.0      # typical; see docs for the stack-up note

M3_CLEAR_DIA_MM = 3.4
M3_TAP_DIA_MM = 2.6
M3_HEAD_DIA_MM = 6.5
M3_HEAD_H_MM = 3.5
M3_NUT_AF_MM = 5.5
M3_HEATSET_DIA_MM = 4.2            # brass heat-set insert, M3 x 5.0 mm long
M3_HEATSET_DEPTH_MM = 5.5
M3_HEATSET_THRU_DIA_MM = 3.2
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

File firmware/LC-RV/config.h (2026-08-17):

/* LC-RV configuration -- this is the only file you should need to edit.
   Change CALIBRATION_FACTOR to the number printed by
   firmware/calibration/calibrate, and BOB_DIAMETER_MM if you installed one
   of the other bobs. */

#ifndef LCRV_CONFIG_H
#define LCRV_CONFIG_H

/* ---- Pins (Arduino Nano) ------------------------------------------- */
#define PIN_TACHO      2      /* IR sensor OUT, INT0                    */
#define PIN_HX711_DT   3
#define PIN_HX711_SCK  4
#define PIN_DIR        8      /* A4988 DIR                              */
#define PIN_STEP       9      /* A4988 STEP -- must be D9, it is OC1A   */
#define PIN_POT       A0      /* speed potentiometer wiper              */
#define OLED_ADDR   0x3C      /* SSD1306 on A4/A5, fixed by the TWI pins */

/* ---- Geometry, millimetres ----------------------------------------- */
/* 43.0 gives the 1.5 mm gap; the spare bobs are 40.0 / 37.0 / 34.0.    */
#define BOB_DIAMETER_MM   43.0
#define CUP_RADIUS_MM     23.0
#define WETTED_HEIGHT_MM  30.0
/* Annular gap G = R_c - R_b, so 1.5 mm with the 43 mm bob.            */
#define GAP_MM   (CUP_RADIUS_MM - 0.5 * BOB_DIAMETER_MM)

/* ---- Calibration ---------------------------------------------------- */
/* Raw HX711 counts per gram, from calibrate.ino.  A 100 g cell at
   1 mV/V on 5 V lands near 2e4; the value below is a placeholder,
   replace it with your own.                                           */
#define CALIBRATION_FACTOR  21000.0

/* ---- Hardware ------------------------------------------------------- */
#define LOADCELL_CAPACITY_G 100.0  /* printed rating of the cell        */
#define STEPS_PER_REV       3200   /* 200 full steps x 1/16 microstep   */
#define IR_PULSES_PER_REV   20     /* slots in the printed encoder disc */

#endif /* LCRV_CONFIG_H */

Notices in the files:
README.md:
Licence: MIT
